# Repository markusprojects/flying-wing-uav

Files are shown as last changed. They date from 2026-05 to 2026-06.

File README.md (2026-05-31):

# Flying Wing UAV: Custom Design & CFD Analysis

> A 1.1 m flying wing drone designed from scratch in Fusion 360, validated with ANSYS Fluent CFD, and built with 3D printing. Inspired by the Skywalker X8.

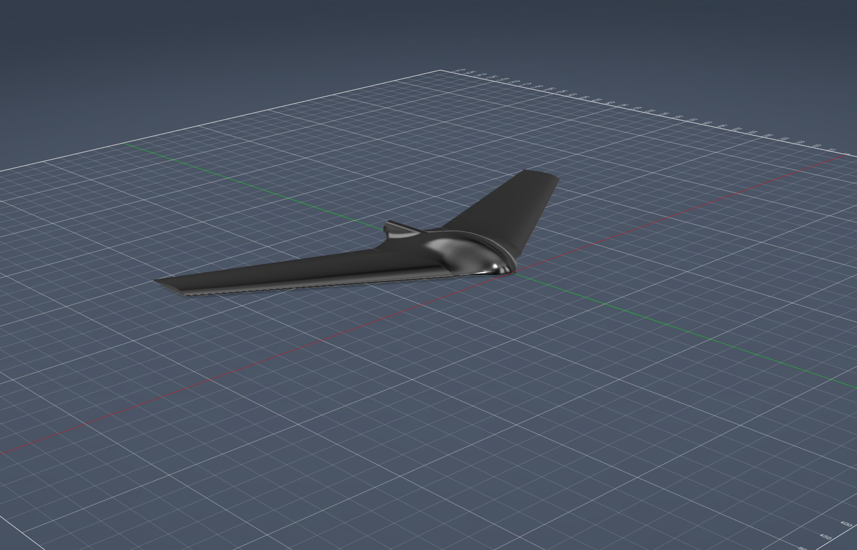
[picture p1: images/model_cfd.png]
CFD-Ready


## Overview

This project documents the end-to-end engineering of a custom flying wing UAV: from aerodynamic concept selection, through CAD modeling and CFD validation, to manufacturing and flight testing. The goal was to design an efficient, payload-capable airframe while learning the full UAV development pipeline.

**Why a flying wing?** Compared to conventional configurations, flying wings offer a higher lift-to-drag ratio for a given wingspan because the entire airframe contributes to lift, there is no tail or fuselage that only adds drag. This makes them ideal for endurance and payload missions.

## Specifications

| Parameter | Value |
| --- | --- |
| Wingspan | 1100 mm |
| Pod width | 200 mm |
| Effective half-span | 450 mm per side |
| Root chord (at pod edge) | 250.88 mm |
| Tip chord | 120 mm |
| Taper ratio | 0.478 |
| Reference area | ~0.244 m² |
| Aspect ratio | ~4.96 |
| Sweep angle | 33° |
| Dihedral | 5° |
| Washout | 2° |
| Airfoil | MH 45 (reflexed) |
| Target MTOW | ~800 g |
| Max MTOW | ~1000 g |
| Target payload | ~190 g |
| Target cruise speed | 60–80 km/h |
| Target L/D | > 10 |
| Est. stall speed | ~34–43 km/h |
| Target CG (maiden) | ~158 mm from root LE |

## Design Highlights

- **MH 45 reflexed airfoil** selected for its positive pitching moment (Cm0 > 0), which provides natural pitch stability without a horizontal tail
- **33° leading-edge sweep** gives passive pitch stability
- **2° washout (geometric twist)** prevents tip stall, critical for safe flight at high angles of attack
- **Removable wings** wings attach to a central pod via 8 mm carbon spar plus M4 wing bolts for transport and easy maintenance
- **Rear boom with pusher motor.** A tail boom extends rearward from the central pod on the aircraft centerline (X = 0) and carries the pusher motor at its end. 

## A Note on Winglets

Winglets were part of the early concept (for induced drag reduction and added yaw stability) but have been dropped from the current design. The reasons:

- The wing to winglet junction repeatedly caused unclean geometry in Fusion 360 and, downstream, surface intersection and meshing failures in ANSYS. The junction was never fully watertight, which compromised both the CAD model and the CFD mesh.
- The 33 deg sweep already provides a usable baseline of directional stability, so the airframe is flyable without winglets for a first prototype.
- For the maiden flight the priority is a clean, printable, and simulatable airframe. Removing the winglets eliminates the most problematic geometry on the model and lets the first build and first CFD run proceed on solid ground.
- Winglets can be retrofitted later as a bolt on or reprinted tip section once a clean junction geometry is worked out, without changing the core wing.

In short: the winglets were costing far more in geometry and meshing trouble than they were returning for a first flying prototype, so they were cut to get a reliable airframe into the air.

## Tools Used

- **CAD** Fusion 360
- **CFD** ANSYS Fluent
- **Flight Controller** 
- **Slicing** 
- **Manufacturing**

## Documentation

The full engineering process is documented in the `docs/` folder:

1. [Design Rationale](docs/01-design.md) aerodynamic decisions, sizing
2. [CAD Workflow](docs/02-cad.md) step-by-step Fusion 360 modeling
3. [CFD Analysis](docs/03-cfd.md) ANSYS Fluent setup and results
4. [Build & Manufacturing](docs/04-build.md) print settings, assembly
5. [Electronics & Avionics](docs/05-electronics.md) components, wiring, FC tuning
6. [Flight Testing](docs/06-flight.md) maiden flight, telemetry

## Project Status

- [x] Concept & sizing
- [x] CAD model (Fusion 360)
- [x] Pod design
- [ ] Servo bays & control surfaces refinement
- [x] CFD analysis (ANSYS Fluent)
- [ ] 3D printing & assembly
- [ ] Electronics integration
- [ ] Maiden flight

## Authors

**Markus T. & Tobias W.** 
Project kick-off: April 2026

## Acknowledgments

- Skywalker X8 design inspiration
- Martin Hepperle MH 45 airfoil

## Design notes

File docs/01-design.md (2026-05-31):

# Aerodynamic Design Rationale

This document explains the key aerodynamic decisions made during the design of the flying wing, including trade-offs considered and reasoning behind each choice.

---

## 1. Configuration: Why a Flying Wing?

A flying wing eliminates the conventional fuselage and tail assembly. Every part of the airframe contributes to lift, unlike a conventional aircraft where the fuselage and tail produce only drag and downforce respectively.

**Advantages for our use case:**
- Higher lift to drag ratio (L/D) for a given wingspan
- Lower wetted area, so less skin friction drag
- Simpler structure, so a lighter airframe and more payload capacity
**Disadvantages we had to address:**
- Inherently pitch sensitive without careful design, solved with a reflexed airfoil plus sweep
- No rudder, so directional stability relies on sweep (winglets were dropped, see Section 8)
- Limited payload volume, solved with the integrated pod design

**Inspiration:** Skywalker X8: a proven 2.1m flying wing platform widely used in UAV research and FPV. We scaled the design approach to 1.1m wingspan.

---

## 2. Airfoil MH 45

**Selected airfoil:** MH 45 (Martin Hepperle, 1990s)

**Why MH 45?**
The most critical requirement for a tailless flying wing is a **positive pitching moment coefficient (Cm0 > 0)**. Conventional airfoils (e.g. NACA 2412) have negative Cm0, meaning they pitch nose-down without a tail to counteract it. A reflexed airfoil solves this by curving the trailing edge upward, shifting the center of pressure forward.

MH 45 was specifically designed for flying wings and offers:
- Positive Cm0 -> self-stabilizing in pitch
- Good L/D at chord Reynolds numbers corresponding to our cruise speed (~60–80 km/h)
- Well-documented performance data from airfoiltools.com

### Reynolds Number
 
The chord Reynolds number determines which airfoil performs best. Two reference lengths are used in this project, which is why two slightly different Reynolds numbers appear:
 
Re = (v * c) / nu
 
| Reference length | Value | Reynolds number | Used in |
|---|---|---|---|
| Root chord c = 0.25 m | cruise sizing | approx. 330,000 | this design doc |
| Mean aerodynamic chord c = 0.1931 m | CFD reference | approx. 264,000 | CFD doc |
 
(v = 20 m/s, nu = 1.5e-5 m2/s for air at 15 C.)
 
Both place the wing in the low Reynolds regime (about 100k to 500k), the range MH 45 was optimized for. The CFD uses the MAC as the reference length by convention, which is why its Reynolds number is lower than the root chord based value quoted here.

**Alternatives considered:**

| Airfoil | Cm0 | Notes |
|---|-----|---|
| MH 45 | Positive | **Selected** best balanced for wingspans under 2m, 9.85% thickness |
| MH 60 | Positive | Lower Cm0 than MH45 -> requires more washout for same stability level. Potential candidate for future iterations |
| S5010 | Positive | Also used in flying wings, similar size class |

---

## 3. Planform Geometry

### Overall Layout
The wing consists of three sections:
- **Central pod:** 200mm wide, integrated fuselage containing avionics and battery
- **Left/right half-wings:** each 450mm in span
- **Total wingspan:** 1100mm

This X8-inspired integrated pod design reduces aerodynamic drag compared to a separately mounted pod, while keeping the wing structurally simple.

### Chord Distribution

| Location | Z position | Chord |
|---|---|---|
| Pod edge / wing root | 100mm | 250.88mm |
| Wingtip | 550mm | 120mm |

Note: The original design had a root chord of 280mm at Z=0. After integrating the pod (cutting the wings at Z=±100mm), the effective wing root chord reduced to 250.88mm.

### Wing Area & Aspect Ratio

| Parameter | Value | Calculation |
|---|---|---|
| Half-wing area (trapezoid) | ~0.0834 m² | (250.88+120)/2 * 0.45 |
| Pod reference area | ~0.077 m² | 385mm * 200mm |
| Total reference area | ~0.244 m² | 2 * 0.0834 + 0.077 |
---

## 4. Sweep Angle - 33°

**Selected: 33° leading-edge sweep**

For a flying wing, sweep provides **pitch stability** by shifting the aerodynamic center rearward relative to the center of gravity. Without sweep, the aircraft would be pitch-unstable.

33° matches the Skywalker X8 geometry and is a well-proven value for this class of aircraft.

**Leading edge offset at Z = 550mm (original tip):**
```
X_offset = 550 * tan(33°) = 357mm
```

---

## 5. Dihedral

A dihedral angle of 5° was incorporated to provide passive roll stability. This reduces reliance on the flight controller for roll correction and improves natural flight behavior, particularly during manual control and in the event of disturbances such as gusts. The flight controller (ArduPlane) provides additional active stabilization on top of this passive baseline.

---

## 6. Washout (Geometric Twist), 2°

**Selected: 2° washout (tip leading edge rotated -2° relative to root)**

A 2° washout ensures that the wing root stalls before the tips. This is critical for tailless aircraft, as it maintains elevon effectiveness during a stall, allowing the flight control system to automatically lower the nose and recover.

```
120*sin(2°) ≈ 4.18mm
```

**Verified in CAD:** After rotating the tip profile by -2°, the trailing edge of the tip profile sits **4mm above the root chordline** confirming the geometric twist is correctly applied.

---

## 7. Propulsion and Rear Boom
 
The aircraft uses a pusher propeller mounted at the rear on a tail boom that extends back from the central pod.
 
**Layout:**
- The boom lies on the aircraft centerline (X = 0), in line with the nose.
- It sits at roughly one third of the pod height from the bottom, so the thrust line passes close to the center of gravity. This keeps the pitch moment from thrust small.
 
The exact thrust line height will be fine tuned against the final CG during assembly, and any small residual pitch trim is handled by the elevons and by adjusting downthrust.

---

## 8. Weight Estimation

| Component | Estimated Mass |
|---|---|
| Wings 3D printed | ~250g |
| Pod + electronics tray | ~80g |
| FC + RX + ESC + servos | ~100g |
| Battery (3S 2200mAh LiPo) | ~180g |
| Motor + propeller | ~100g |
| Cables + hardware | ~50g |
| **Total (no payload)** | **~760g** |
| With payload (190g) | **~950g** |

**Target MTOW: ~800g. Absolute maximum: 1000g.**

At 1000g, the estimated stall speed is safely below 45 km/h, requiring a confident but manageable hand launch. At 800g, stall speed drops significantly, giving plenty of margin for slow flight and landing.

### Wing Loading

| MTOW | Wing Loading |
|---|---|
| 800g | ~32.8 g/dm² | 
| 1000g | ~41.0 g/dm² | 

---

## 9. Elevons, Design Ongoing

Elevons serve as both elevator and aileron simultaneously. The only control surfaces on a flying wing.

**Geometry:**
- Span: targeting about 20 to 80 percent of the half span (exact Z positions to be finalized)
- Chord: about 25 percent of the local wing chord
- Clearance gap: 1 mm for hinging

**Note for CFD:** A gap-free version of the model (elevons merged into wing) is used for aerodynamic simulation. The 1mm gap is included in the build model only.

---

## 10. Center of Gravity (CG) Target

The Center of Gravity is the most critical parameter for a tailless flying wing. A CG too far aft will result in an uncontrollable aircraft. The CG is calculated based on the Mean Aerodynamic Chord (MAC) of the swept wing panels.

**Calculated Aerodynamic Parameters using ecalc.ch:**
* **Mean Aerodynamic Chord (MAC):** 193.1 mm
* **MAC Z-Position:** 198.5 mm from the pod edge
* **MAC Leading Edge Offset:** 128.9 mm (distance behind the root leading edge due to 33° sweep)

### Target CG Positions
All measurements are taken from the **Leading Edge of the wing root** (exactly where the wing meets the pod at Z=100mm), measuring straight back towards the trailing edge.

| Parameter | % of MAC | Distance from Root LE | Notes for Flight Testing |
|---|---|---|---|
| **Calculated Forward Limit** | 15% | **~158 mm** | **Target for Maiden Flight.** Expected to be highly pitch-stable. |
| **Calculated Aft Limit** | 20% | **~168 mm** | Theoretical rearward limit. |
| **Expected Cruise Sweetspot** | ~17-18% | **~162–164 mm** | To be found during test flights by slowly moving the battery. |

## 11. Summary of Key Parameters

| Parameter | Value |
|---|---|
| Wingspan | 1100mm |
| Pod width | 200mm |
| Effective half-span | 450mm |
| Root chord (at Z=100) | 250.88mm |
| Tip chord (at Z=550) | 120mm |
| Reference area | ~0.244 m² |
| Sweep | 33° |
| Washout | 2° |
| Airfoil | MH 45 (reflexed) |
| Target MTOW | ~800g |
| Max MTOW | ~1000g |
| Target L/D | > 10 |
| Cruise speed | 60–80 km/h |
| Estimated stall speed | ~34–43 km/h |
| Target CG (Maiden) | ~158mm from Root LE |

## 12. Remaining Design Tasks

The current model is prepared for CFD analysis. The following features are still pending for the final build model:

### Mechanical
- [ ] Servo bays cutouts for 2× 9g servos (one per elevon)
- [ ] Motor mount pusher configuration at pod rear
- [ ] Electronics tray
- [ ] Wing-pod attachment 
- [ ] Print segmentation

### Aerodynamic
- [ ] Elevon geometry

## Background & Preparation

Before starting the design, we worked through the aerodynamic fundamentals 
from scratch. Such as airfoil theory, reflexed profiles, wing twist, elliptical lift 
distribution, and the specific challenges of tailless configurations.

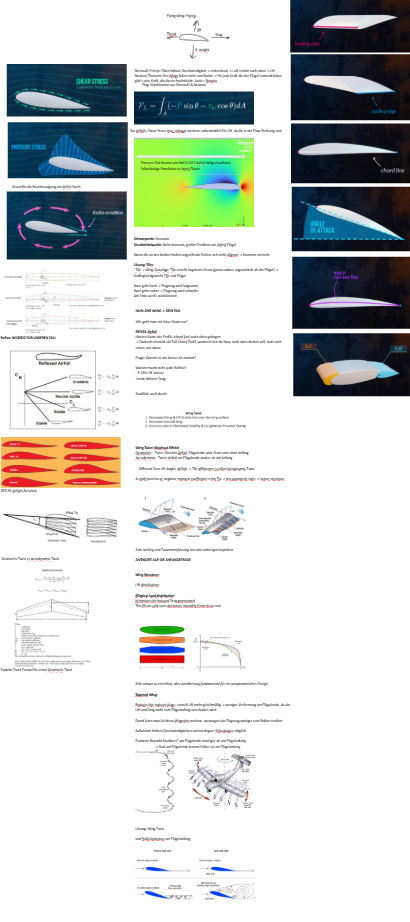
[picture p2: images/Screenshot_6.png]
Study notes


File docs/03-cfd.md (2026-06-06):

# CFD Analysis, ANSYS Fluent

This document covers the full CFD workflow for the flying wing: geometry preparation, mesh generation, solver setup, and the angle of attack polar used to assess aerodynamic performance and static stability.

**Software:** ANSYS Fluent 2026 R1 (Student License)
**Validation:** XFLR5
**Geometry input:** `cad/flying-wing.step`

**Status:** NEW POLAR INCOMING! First angle of attack polar complete (0 to 10 degrees). Cross-checked against XFLR5; a refined-mesh spot check indicates the polar below under-predicts lift.
 
> **Note:** The ANSYS Student License is limited to 1,048,576 cells. This constraint influenced most meshing decisions below.

---

## Objectives

- Determine lift and drag coefficients (CL, CD) across the operating angle of attack range
- Build a polar curve and assess static stability via the pitching moment Cm
- Detect the onset of flow separation or pitch up
- Provide first order aerodynamic data to support the CG and stability layout

---

## Simulation Setup

### Geometry Preparation (Discovery)

The STEP file exported from Fusion 360 was imported into ANSYS Discovery for geometry validation. The model is the full flying wing including the central pod and the rear boom (no symmetry split). The wing solid was removed from the enclosure volume, leaving a fluid domain with a wing shaped cavity. The enclosure body was explicitly set to **Fluid**.

The enclosure was split into named boundary regions directly on the enclosure faces:

| Region | Boundary type | 
|---|---|
| inlet | velocity inlet | 
| outlet | pressure outlet | 
| farfield | symmetry | 
| wing | wall (no slip) | 

Angle of attack was applied aerodynamically by tilting the inlet velocity vector, not by rotating the geometry. This keeps a single mesh valid for every angle of attack.

---

### Mesh

The final working mesh used a uniform coarse global size, a finer local size on the wing surface, and a thin inflation layer to begin resolving the boundary layer:

| Parameter | Value |
|---|---|
| Physics / Solver preference | CFD / Fluent |
| Global element size | 200 mm |
| Wing surface (Named Selection) | 10 mm face sizing |
| Inflation (wing) | 5 layers, first layer 0.3 mm, growth rate 1.2 |
| Smoothing | High |
| Nodes | 117,698 |
| Elements | 517,381 |
| Average skewness | 0.260 (good) |
| Max skewness | 0.998 (single element at the trailing edge) |
| Wall y+ (average) | 8.0 |
| Wall y+ (maximum) | 20.0 |

The skewness histogram shows the bulk of elements between 0.13 and 0.45, which is healthy for an unstructured tetrahedral mesh. The maximum of 0.998 is a single degenerate element at the sharp trailing edge and does not affect overall solution stability. Refining the global mesh was observed to lower skewness further.

The wall y+ on the wing has an average of about 8 and a maximum of about 20. For the k-omega SST model this sits in the buffer layer, between the low y+ range (below 1, boundary layer fully resolved) and the wall function range (above 30). In this intermediate range neither approach is fully valid, which means the wall shear stress and therefore the viscous drag are only approximate. This is the main reason the absolute drag values below should be treated as first order estimates rather than precise figures.

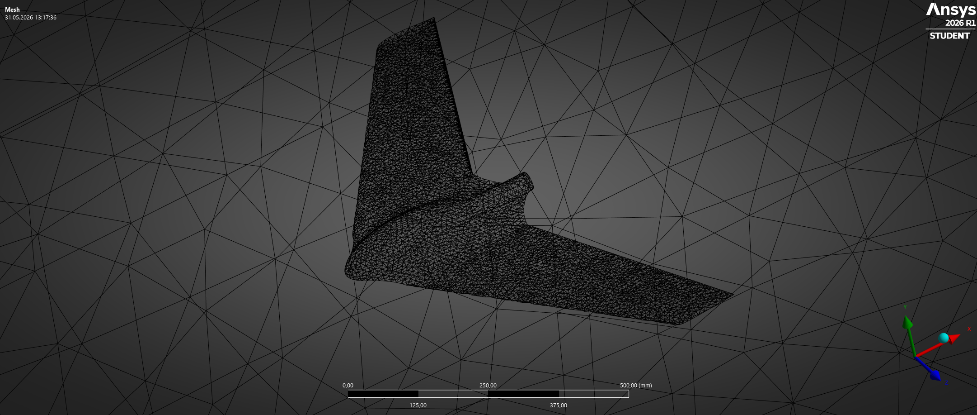
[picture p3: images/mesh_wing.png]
Mesh on wing surface
> 
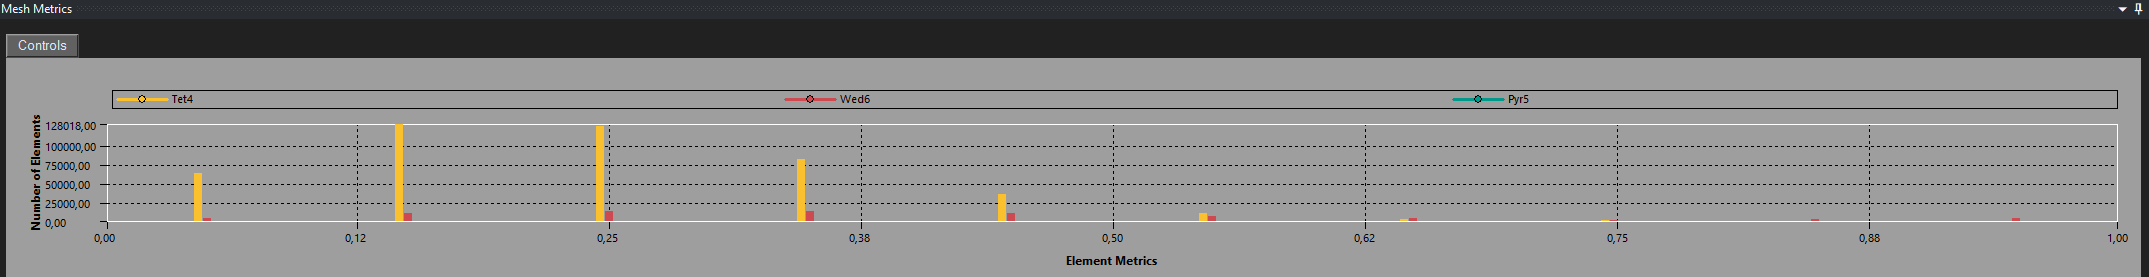
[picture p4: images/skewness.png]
Skewness metric
> 

---

### Fluent Setup

| Parameter | Value |
|---|---|
| Solver | Pressure based, Steady |
| Turbulence model | k-omega SST |
| Reference area (A) | 0.229 m2 (projected planform) |
| Reference length (MAC) | 0.1931 m |
| Freestream velocity | 20 m/s |
| Density | 1.225 kg/m3 |
| Viscosity | 1.7894e-5 kg/(m s) |
| Reynolds number | approx. 264,000 |
| Turbulent intensity | 0.1 percent |
| Turbulent viscosity ratio | 10 |
| Pressure velocity coupling | SIMPLE |
| Gradient | Least Squares Cell Based |
| Spatial discretization | Second Order Upwind (momentum, k, omega, pressure) |
| Moment center | x = 0.226 m, moment axis (0, 0, 1) |

#### Angle of attack via inlet components

Velocity magnitude was held constant at 20 m/s, the angle was set through the X and Y components. The lift and drag report direction vectors were rotated by the same angle so that drag stays parallel to the freestream and lift perpendicular to it. The moment axis (spanwise, Z) is unchanged for all angles.

| AoA | Inlet X | Inlet Y | Drag direction (cos a, sin a, 0) | Lift direction (minus sin a, cos a, 0) |
|-----|---|---|---|---|
| 0 deg | 20.000 | 0.000 | (1.0000, 0.0000, 0) | (0.0000, 1.0000, 0) |
| 3 deg | 19.973 | 1.047 | (0.9986, 0.0523, 0) | (-0.0523, 0.9986, 0) |
| 5 deg | 19.924 | 1.743 | (0.9962, 0.0872, 0) | (-0.0872, 0.9962, 0) |
| 7 deg | 19.851 | 2.437 | (0.9925, 0.1219, 0) | (-0.1219, 0.9925, 0) |
| 10 deg | 19.696 | 3.473 | (0.9848, 0.1736, 0) | (-0.1736, 0.9848, 0) |

#### Convergence approach

First order upwind was used to establish a stable initial field, then momentum, k and omega were switched to second order on the converged field without re-initialising. Second order was essential: switching from first to second order on the 0 degree case reduced CD by roughly 37 percent (the first order result was artificially diffusive). Subsequent angle of attack cases were started from the previous converged solution rather than re-initialised, which converged faster.

---

## Results

### Aerodynamic Polar

All values at V = 20 m/s, Re approx. 264,000, fully second order, moment about x = 0.226 m.

| AoA | CL | CD | L/D | Cm |
|-----|---|---|---|---|
| 0 deg | 0.0567 | 0.0195 | 2.91 | -0.0035 |
| 3 deg | 0.1029 | 0.0237 | 4.34 | -0.0048 |
| 5 deg | 0.1339 | 0.0288 | 4.65 | -0.0052 |
| 7 deg | 0.1858 | 0.0372 | 4.99 | +0.0041 (unconverged, see note) |
| 10 deg | 0.2153 | 0.0500 | 4.31 | -0.0060 |

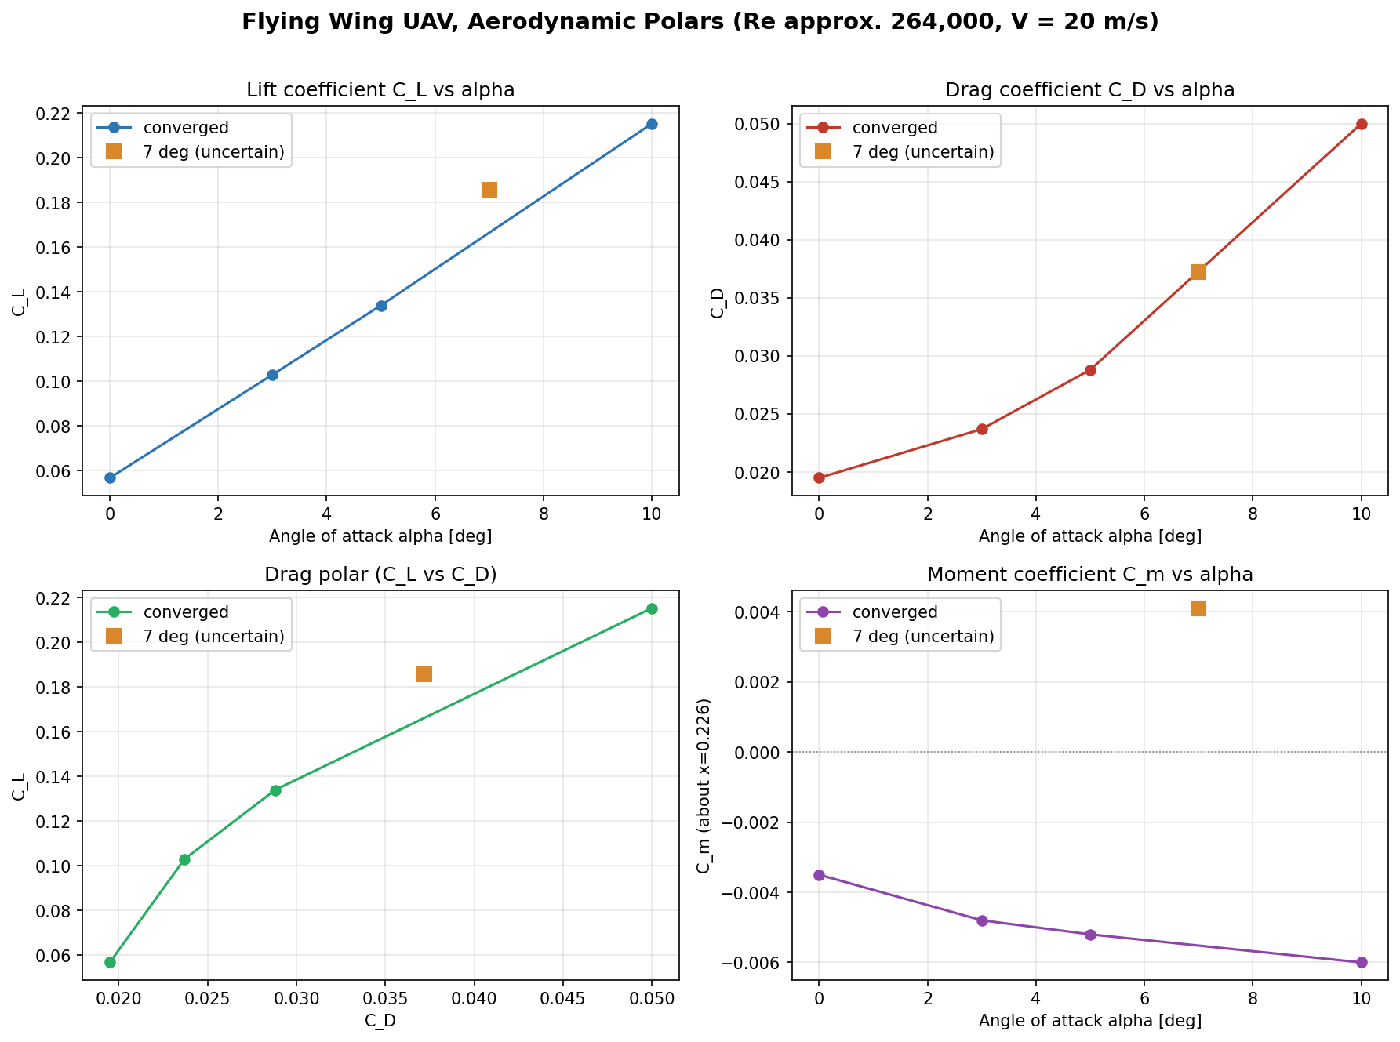
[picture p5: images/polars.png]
Polar curves
> 

CL rises monotonically and approximately linearly with angle of attack (dCL/da approx. 0.015 per degree), which is physically consistent. CD rises as expected. L/D peaks in the mid angle of attack range.

The absolute L/D values are modest for a wing. This is attributed to the viscous drag being overestimated by the coarse boundary layer resolution. As measured above, the wall y+ averages about 8 (max 20), which falls in the buffer layer where the SST model neither fully resolves the boundary layer nor cleanly applies wall functions, so the wall shear is approximate. The trends and coefficients are reliable as first order data, the absolute drag should be treated with caution and would improve with a finer near wall mesh (target y+ below 1).

---

### Pitching Moment and Static Stability

Cm about x = 0.226 m is negative and becoming more negative from 0 to 5 degrees (-0.0035 to -0.0052). A restoring nose down moment that strengthens with increasing angle of attack is the signature of a statically stable configuration, exactly what is required for a tailless flying wing.

The 7 degree point breaks this trend with Cm = +0.0041, but this case did not fully converge. The residuals climbed after about 600 iterations and the force values oscillated, indicating mildly unsteady flow. The 10 degree point returns to Cm = -0.0060, in line with the lower angle trend. The non monotonic Cm at 7 degrees is therefore most likely a numerical artefact of an unconverged, mildly unsteady solution rather than a true pitch up event. The 7 degree case should be re-run (lower under relaxation factors, a force monitor on Cm, more iterations) before being used quantitatively.

Taking the converged points (0, 3, 5, 10 degrees), the configuration shows stable static pitch behaviour across the tested range.

---

### Pressure Distribution

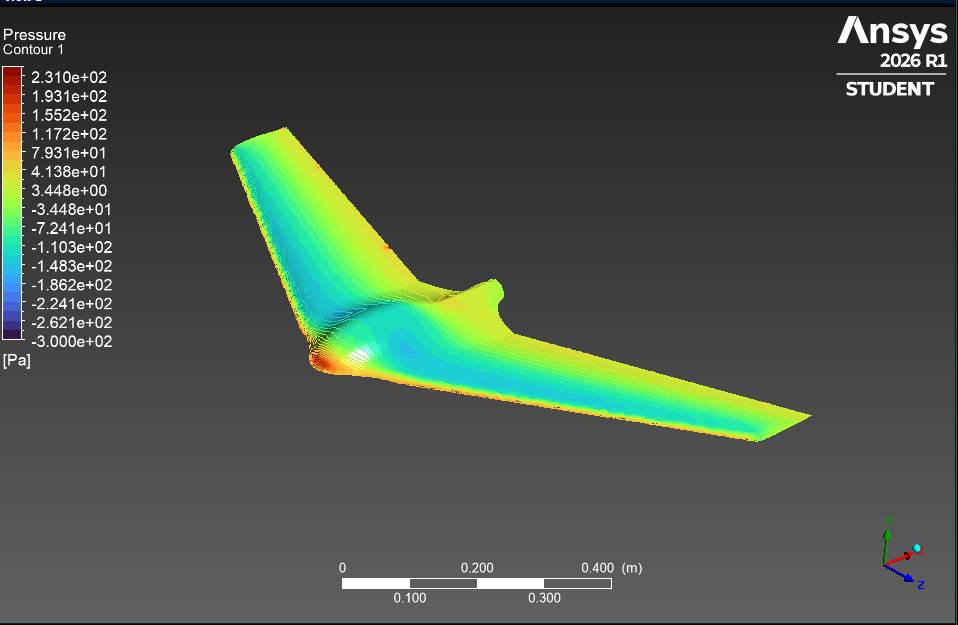
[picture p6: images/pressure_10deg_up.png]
Pressure distribution at 10 degrees AoA
> 
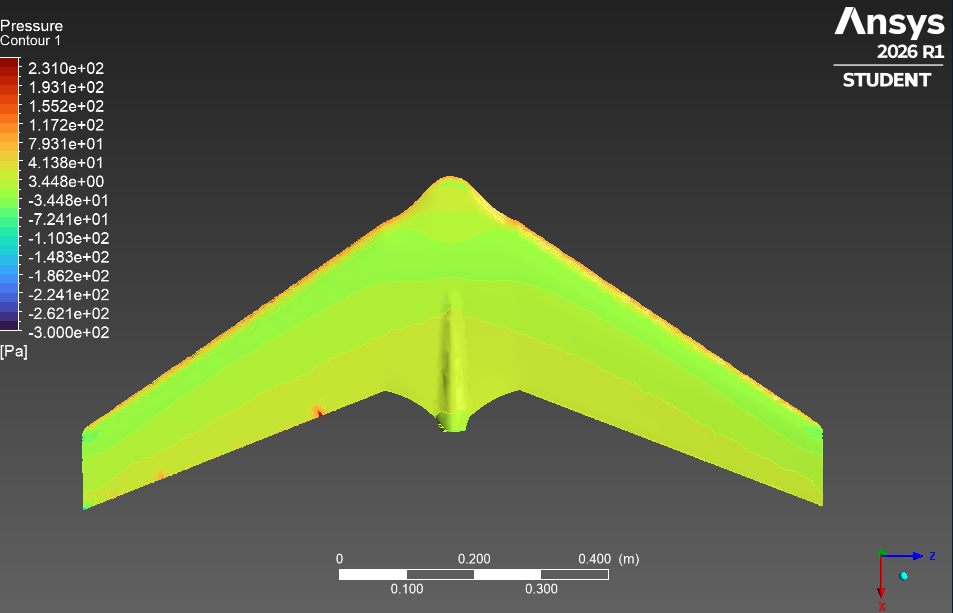
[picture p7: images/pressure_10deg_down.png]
Pressure distribution at 10 degrees AoA
> 
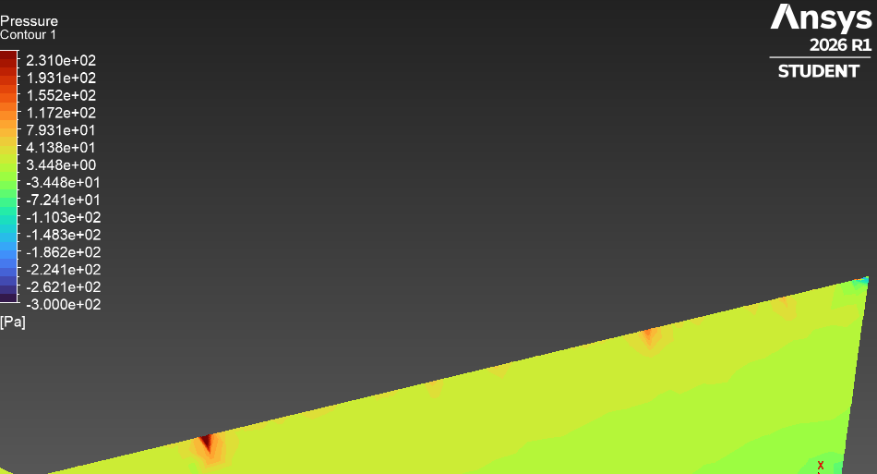
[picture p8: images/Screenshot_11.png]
> 

The pressure field at 10 degrees angle of attack is physically consistent: stagnation and high pressure on the lower surface near the leading edge, strong suction on the upper surface concentrated toward the leading edge, and pressure recovery toward the trailing edge. A local pressure disturbance is visible at the pod to wing junction, expected given the geometric transition there. A few isolated, sharp pressure spikes appear at the trailing edge that do not match their smooth surroundings, these are numerical artefacts from the most distorted elements (skewness near 1) rather than real flow features, and being single cells among hundreds of thousands they have a negligible effect on the integrated forces.

## Validation: XFLR5 Cross-Check and Mesh Sensitivity
 
To check whether the polar above is physically reasonable, the lift-curve slope was compared against an independent method, and a single angle of attack was re-run on a finer mesh.
 
### Lift-curve slope vs. theory and XFLR5
 
The polar above gives a lift-curve slope of approximately **0.0155 per degree**. For this planform (aspect ratio ~4.85, quarter-chord sweep ~30 deg, MH 45 section), finite-wing theory predicts roughly **0.045-0.05 per degree**, which about three times higher.
 
The wing was rebuilt in **XFLR5** from the design parameters and analysed with the vortex-lattice method (VLM1). XFLR5 confirmed the geometry (aspect ratio 4.85, root-to-tip sweep 29.95 deg, taper 0.48, MAC 0.19 m) and returned a clean, near-linear CL-alpha curve reaching **CL ~= 0.48 at 10 deg**, i.e. a slope of **~0.048 per degree**, with a stable (negative) Cm-alpha slope. This is consistent with theory and roughly three times the CFD slope above.
 
The MH 45 section was also checked against published XFOIL data (airfoiltools.com, Re 200k, Ncrit 9): 2D section slope ~0.103 per degree with positive Cm0, confirming the airfoil itself is healthy. The conclusion is that the original mesh under-predicts lift, and the deficit is a CFD resolution issue, not a geometry or airfoil problem.
 
### Refined-mesh spot check (5 deg)
 
A finer wing surface mesh (7 mm faces with curvature capture, increased inflation layer count) was generated to better resolve the leading-edge suction peak, where most of the circulation is produced. The 5 deg case was re-run on this mesh:
 
| Quantity (5 deg) | Original mesh | Refined mesh |
|---|---|---|
| CL | 0.1339 | **0.1355** |
| Lift force | ~3.2 N | **7.60 N** |
 
The refined single-point result is consistent with the XFLR5 prediction, supporting the conclusion that resolving the leading-edge suction peak recovers the missing lift. A full refined polar is required to quantify the final slope.

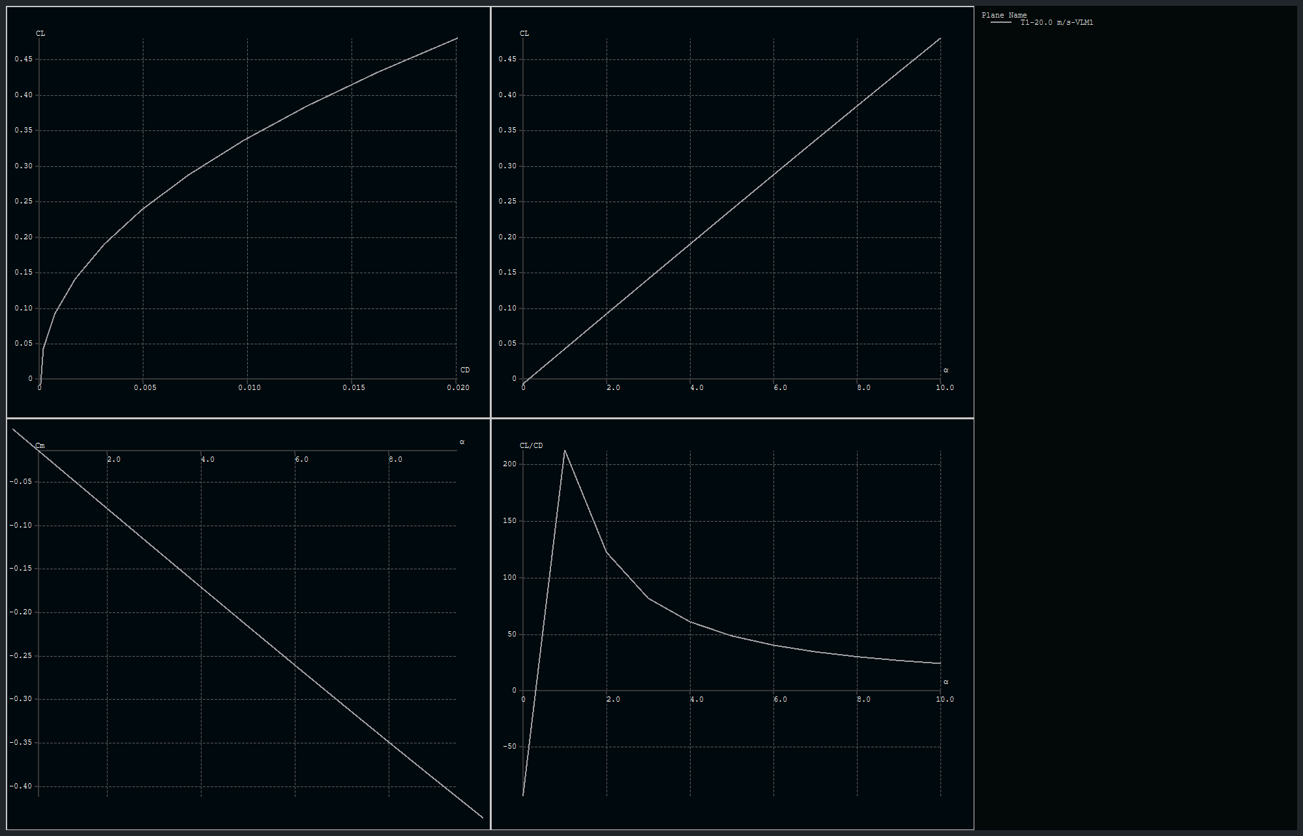
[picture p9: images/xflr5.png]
XFLR5 Validation
> 

### What this means for the data above
 
- **Lift trends and stability (Cm)** are directionally reliable and confirmed stable by XFLR5.
- **Absolute lift** from the original polar is under-predicted; the XFLR5 slope (~0.048 /deg) is the better estimate until a full refined polar is run.
- **Absolute drag / L-D** remains first order (y+ ~8, fully-turbulent SST at low Re).
---

## Challenges and What We Learned

### Tip profiles not contained in the wing body

The first attempt produced force coefficients in the 10^6 range and violently oscillating residuals. The cause was that the wing tip profile faces were not part of the closed wing body. They formed open faces, so the corresponding boundaries were undefined and the solver produced meaningless values. Rebuilding the geometry with all tip profiles correctly contained in the wing body resolved it.

**Lesson:** Before meshing, confirm the wing body is fully closed. Open faces at tips or trailing edges give garbage CFD results, not just mesh failures.

### Enclosure not set to Fluid

Early meshes failed with no clear error message because the enclosure body was not explicitly set to Fluid in Discovery. The mesher could not determine which region was the flow domain.

**Lesson:** Always set the enclosure body to Fluid in Discovery before exporting. It is not automatic and there is no warning if it is missing.

### Student License cell limit

A 100 mm global mesh produced over 5 million elements, five times the limit. Reaching a usable count required tuning enclosure size and global sizing together. The final mesh (200 mm global, 10 mm on the wing, light inflation) came in at about 517,000 elements, comfortably within the limit.

**Lesson:** With a Student License, external aerodynamics sits at the edge of what is feasible. Enclosure size directly drives cell count, a smaller domain and coarse global sizing are necessary, at some cost to far field accuracy.

### Mesh failures with mixed sizing (no real fix yet found)

Combining a fine wing face sizing with a coarse global sizing repeatedly failed with the message that one or more surfaces could not be meshed with acceptable quality. The same settings sometimes worked after a restart and failed again unchanged. A working mesh was eventually achieved by establishing a stable base mesh first and applying local sizing and inflation carefully on top.

**Lesson:** On complex lofted geometry, get a uniform base mesh working before adding mixed sizing. Restart Meshing when behaviour becomes inconsistent.

### ANSYS Meshing inconsistency

Identical settings produced different results across sessions. A mesh that generated at one size would fail at another, then fail at the original after reapplication. Clearing generated data and restarting Workbench sometimes resolved failures without any setting change.

**Lesson:** When Meshing fails unexpectedly, clear generated data and restart Workbench before changing settings.

### Refining only the wing raised skewness
 
Refining just the wing surface to capture the geometry better actually increased skewness, because the large size jump between the fine wing cells and the coarse surrounding cells distorted the elements in the transition region. Skewness only improved when the global mesh was refined together with the wing, which in turn drove the cell count up toward the Student License limit.
 
**Lesson:** Local refinement cannot be decoupled from the surrounding mesh. Lowering skewness needs the global and local sizes refined together, so it is a direct trade-off against the cell limit.

### Solver divergence when changing schemes or initialising

Switching to second order on a freshly initialised field, or re-initialising after a scheme change, caused immediate divergence and once froze Fluent. Changing both turbulence intensity and discretisation order at the same time made the cause impossible to isolate.

**Lesson:** Change one thing at a time. Save Case and Data as a recovery point, switch to second order only on an already converged field without re-initialising, and reload the data instead of re-initialising if a run diverges.

### Validate absolute values against an independent method
 
The polar looked internally consistent (smooth, monotonic, physically sensible trends) yet under-predicted lift by ~3x. This was only caught by comparing the lift-curve slope against finite-wing theory and an XFLR5 vortex-lattice analysis. A CFD result can converge cleanly and still be quantitatively wrong.
 
**Lesson:** Cross-check key coefficients against an independent method (theory, XFLR5, published data) before trusting absolute values.
---

- Re-run the 7 degree case to convergence (lower under relaxation, force monitor on Cm) to confirm whether the positive Cm is real or numerical
- Determine the neutral point from the converged dCm/dCL slope and compute the static margin against the estimated CG
- Refine the near wall mesh to a low y+

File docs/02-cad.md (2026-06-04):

# CAD Workflow Fusion 360
 
This document describes the modeling process for the flying wing in Fusion 360. It covers the overall approach, the key decisions made along the way, and what didn't work and what we learned from it.
 
**Software:** Autodesk Fusion 360  
**Current model purpose:** CFD geometry only (ANSYS Fluent input)  
**File:** `cad/flying-wing.step`
 
> **Note:** This version of the model is prepared specifically for CFD simulation. It is a solid, closed body, not hollowed, no internal structure, no servo cutouts. The print-ready version will be a separate file developed in a later phase.
 
---
 
## Modeling Approach
 
The wing was built using a loft-based workflow, which gives precise control over the cross-sectional shape across the span. A guide rail (leading edge path) controls the transition geometry between root and tip profiles.
 
**Workflow overview:**
1. Import MH 45 airfoil profile (root)
2. Create offset plane -> sketch scaled tip profile with washout
3. Loft with leading-edge guide rail -> main wing body
4. Add pod geometry as well as guide rails to achieve the wanted pod form
5. Mirror wing to full span
6. Add rear boom (loft guided past a circle sketch, then extrude, trim intersections, fillet)
7. Add holm channel (sweep cut) (Not present in the CFD version)
8. Add winglets (To be redone)
9. Close elevon gaps for CFD (Not present in the CFD version)
---
 
## Key Decisions
 
**Airfoil import:** The MH 45 profile was imported from a `.dat` coordinate file. The raw file leaves a small gap at the trailing edge, this had to be closed manually before the loft would execute.
 
**Washout:** The tip profile was rotated ~2° (trailing edge up) to add geometric washout. In practice this resulted in the tip chord sitting 4mm above the root chordline, verified via Inspect → Measure.

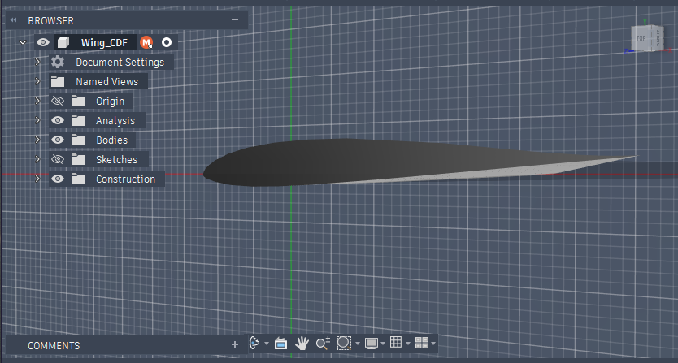
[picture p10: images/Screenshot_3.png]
Washout overview

 
**No shell for CFD:** The model is intentionally left as a solid body. CFD only sees the external surface, internal geometry is irrelevant for external aerodynamics. Hollowing is reserved for the print-ready version.

**Pod creation:** The pod body was created via the pod profile sketch to be lofted to the root of the wing. Several rails were created to achieve the pod form. In earlier versions the pod was attempted to be build as a seperate body and be assembled ontop of the wing. Not it is fully integrated into the main body.

**Rear boom:** the boom was created by sketching a circular profile on the rear face of the pod and lofting from the pod cross section into that circle. Guide rails were constrained tangent to the end circle so the rails close symmetrically into a clean round tail section. The boom lies on the centerline (X = 0) at roughly one third of the pod height, positioned so the pusher motor thrust line passes close to the CG. The boom carries the motor mount at its rear end.

---
 
## Challenges & What We Learned

### 
 
### Winglet geometry errors led to removal
 
The winglets initially showed 20 face intersection errors in ANSYS Discovery. The root cause was an imprecise transition between the winglet extrude and the swept wing surface: the faces were touching but not cleanly joined. Fusion's own geometry check showed no issues, which was misleading.
 
After repeated attempts to clean up the junction, the winglets were removed from the design entirely. The 33 deg sweep already provides a baseline of directional stability, so the airframe is flyable without them for a first prototype, and removing them eliminated the most problematic geometry on the model for both CAD and CFD. They can be revisited later as a reprinted tip section once a clean junction is worked out.
 
**Lesson:** Fusion's internal geometry validation is less strict than what CFD preprocessors require. Always validate the exported STEP in Discovery before starting mesh setup. If a junction cannot be made watertight, it is better to remove the feature than to fight an unclean geometry through meshing.

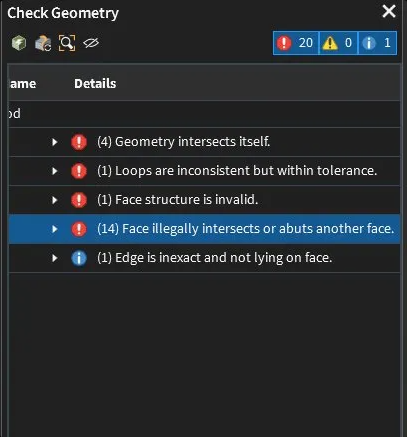
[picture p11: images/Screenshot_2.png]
ANSYS Discovery errors
 
 
---
 
## Current Model State (CFD-ready) (No winglets)

CFD-Ready

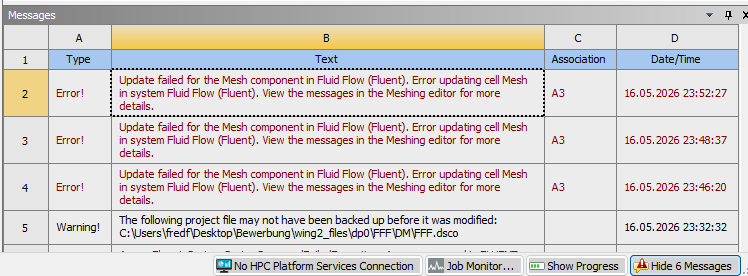
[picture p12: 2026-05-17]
images/Screenshot_7.png

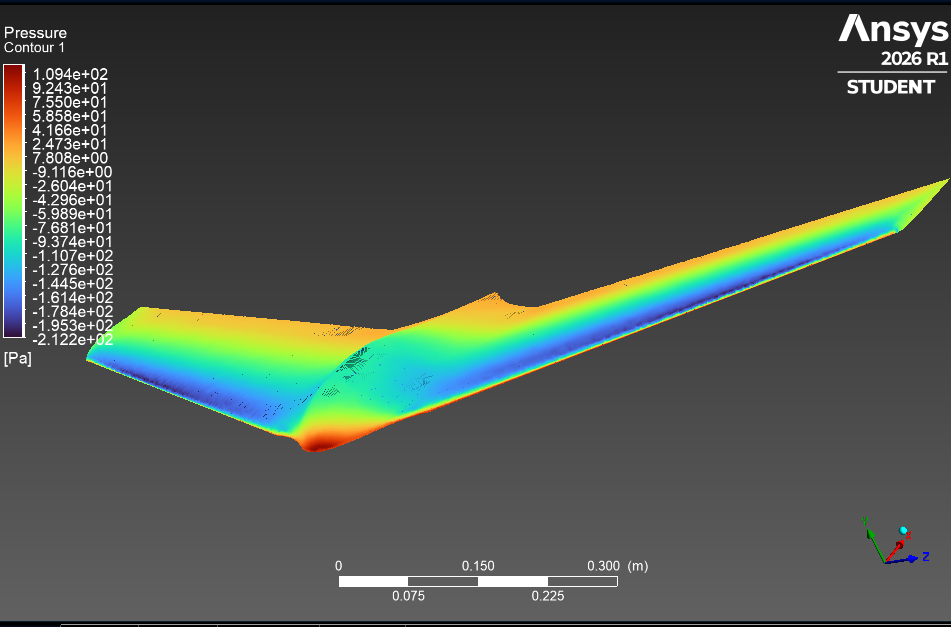
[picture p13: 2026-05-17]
images/pressure_view.png

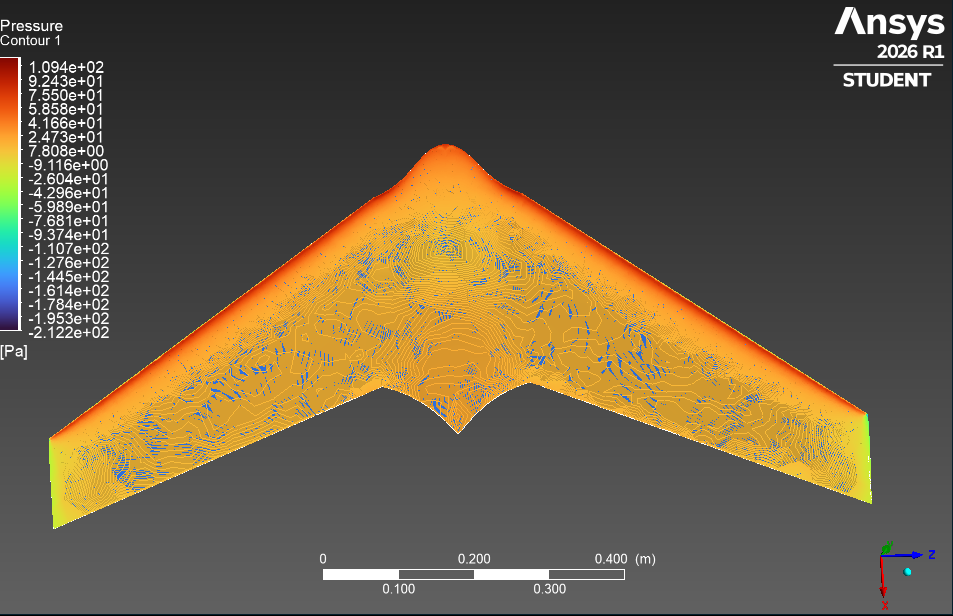
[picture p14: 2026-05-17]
images/pressure_down.png

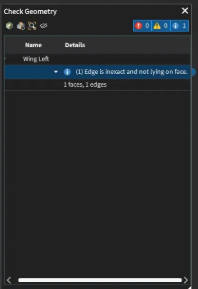
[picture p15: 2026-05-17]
images/Geometry Error.png

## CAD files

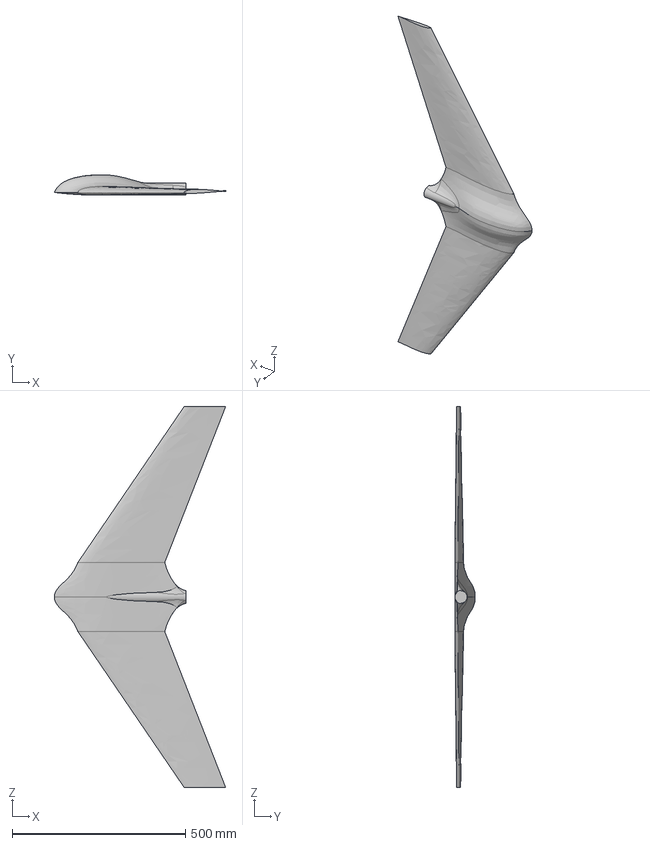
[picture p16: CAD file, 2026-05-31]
cad/Wing_CDF8.step
494.9 x 59.1 x 1100.0 mm

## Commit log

2026-05-31 Update README with rear boom details and winglet removal
    Added details about the rear boom with pusher motor and removed winglets from the design due to geometry issues. Updated notes on winglet considerations and their impact on the prototype.
2026-05-31 Remove duplicate rear boom description from README
    Removed redundant description of the rear boom with pusher motor from the README.
2026-05-31 Revise CAD steps and address winglet geometry issues
    Updated CAD documentation to include new steps for adding a rear boom and revised winglet geometry errors.
2026-05-31 Update CFD-ready image in 02-cad.md
2026-06-04 Update CAD documentation for pod and rear boom
    Corrected formatting of the 'Pod creation' section and added a new 'Rear boom' section detailing its creation and positioning.
